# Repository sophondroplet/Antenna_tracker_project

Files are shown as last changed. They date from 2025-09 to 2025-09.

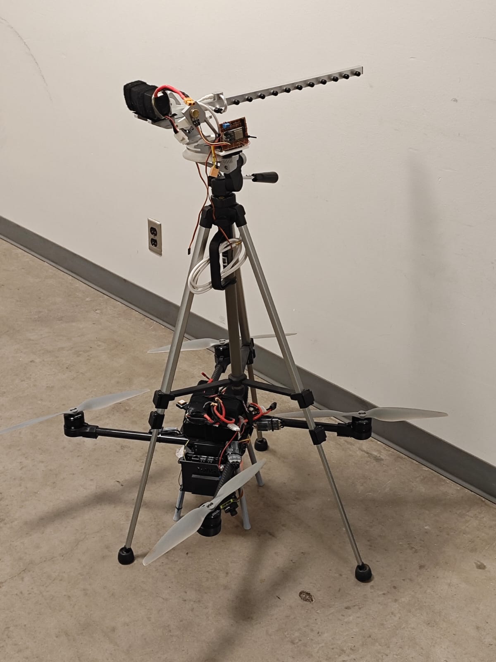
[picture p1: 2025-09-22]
assets/images/atrimg6.jpg

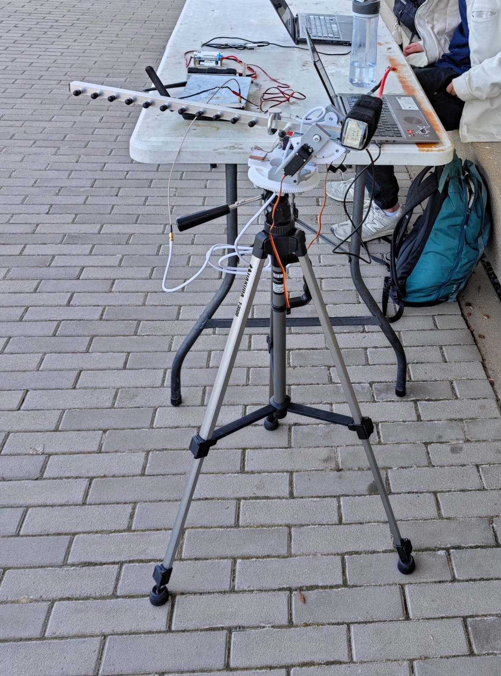
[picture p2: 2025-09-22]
assets/images/atrimg7.jpg

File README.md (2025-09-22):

# Antenna Tracker Project

## Project Overview
The Antenna Tracker Project is designed to track and maintain communication with a moving object, such as a drone or satellite, by dynamically adjusting the orientation of an antenna. This project leverages GPS data, magnetometer calibration, and servo control to achieve precise tracking.

## Directory Structure and File Descriptions

### 1. `GPS_tester/GPS_tester.ino`
This script tests the GPS module by reading and displaying latitude, longitude, and altitude data. It uses the `TinyGPS++` library to parse GPS data and outputs the results via the serial monitor.

### 2. `GPS_tester_send/GPS_tester_send.ino`
Similar to `GPS_tester.ino`, this script reads GPS data but also transmits the raw GPS data over a serial connection. It includes LED indicators for activity.

### 3. `Magentormeter_calibration/Magentormeter_calibration.py`
This Python script calibrates the magnetometer by fitting an ellipsoid to the raw data. It calculates hard iron offsets and soft iron transformation matrices to correct the magnetometer readings. The script uses libraries like `numpy`, `matplotlib`, and `scipy` for data processing and visualization.

### 4. `Main/Main.ino`
The main control script for the antenna tracker. It integrates GPS data, WiFi communication, and servo control to dynamically adjust the antenna's azimuth and elevation. Key features include:
- WiFi setup for communication with a ground station.
- UDP packet handling for receiving GPS coordinates.
- Servo motor control for antenna orientation.
- Calibration parameters for precise tracking.

### 5. `Servo_tester/Servo_tester.ino`
This script tests the servo motors by allowing manual control via the serial monitor. Users can input PWM values to adjust the servo position and observe the response.

### 6. `UDP_GPS_send_tester/UDP_GPS_send_tester.ino`
This script tests the UDP communication by sending GPS data over a network. It ensures that the GPS data can be transmitted and received correctly.

## Additional Resources

### CAD Files
The `CAD_files` directory contains 3D models and components for the antenna tracker. These files can be used for manufacturing or 3D printing the hardware. Key files include:
- `Antenn tracker 3D model.step`: Complete 3D model of the antenna tracker.
- `Antenna_Tracker-elevator gear.step`: Gear for the elevator mechanism.
- `Antenna_Tracker-arm_left.step` and `Antenna_Tracker-arm_right.step`: Left and right arms of the tracker.
- `Antenna_Tracker-battery holder left.step` and `Antenna_Tracker-battery holder right.step`: Battery holders.
- `Antenna_Tracker-Spur gear (18 teeth).step` and `Antenna_Tracker-Spur gear (20 teeth).step`: Spur gears for the mechanism.

### Images
The `assets/images` directory contains images of the project and CAD renderings. These images provide a visual reference for the hardware setup and design. Key images include:
- `atrCAD1.png` to `atrCAD6.png`: Rendered CAD images of the antenna tracker.
- `atrimg1.jpg` to `atrimg7.jpg`: Photos of the assembled hardware and components.

### Usage
- Use the CAD files to 3D print or manufacture the components.
- Refer to the images for assembly guidance and to understand the hardware layout.

## Setup Instructions

### Hardware Requirements
- ESP32 microcontroller
- GPS module (e.g., M10Q-250 or BN-880)
- Magnetometer
- Servo motors for azimuth and elevation control
- WiFi network for communication

### Software Requirements
- Arduino IDE
- Python 3.x
- Required Python libraries: `numpy`, `matplotlib`, `scipy`
- TinyGPS++ library for Arduino
- ESP32Servo library for Arduino

### Steps to Set Up
1. **Install Arduino IDE**
   - Download and install the Arduino IDE from [arduino.cc](https://www.arduino.cc/).

2. **Install Required Libraries**
   - Open the Arduino IDE and go to `Sketch > Include Library > Manage Libraries`.
   - Search for and install the following libraries:
     - `TinyGPS++`
     - `ESP32Servo`

3. **Upload Scripts**
   - Connect the ESP32 to your computer via USB.
   - Open the desired `.ino` file in the Arduino IDE.
   - Select the correct board (`ESP32 Dev Module`) and port from the `Tools` menu.
   - Click the upload button to flash the script onto the ESP32.

4. **Calibrate the Magnetometer**
   - Connect the magnetometer to your computer.
   - Run `Magentormeter_calibration.py` using Python.
   - Follow the on-screen instructions to collect and calibrate data.

5. **Test Components**
   - Use `GPS_tester.ino` to verify GPS functionality.
   - Use `Servo_tester.ino` to test servo motor control.
   - Use `UDP_GPS_send_tester.ino` to test UDP communication.

6. **Run the Main Script**
   - Upload `Main.ino` to the ESP32.
   - Ensure all hardware components are connected.
   - Monitor the serial output for debugging and status updates.

## Notes
- Ensure the GPS module is connected to the correct pins as specified in the scripts.
- Calibration values for the magnetometer and servos may need to be adjusted based on your setup.
- The WiFi credentials in `Main.ino` should be updated to match your network.

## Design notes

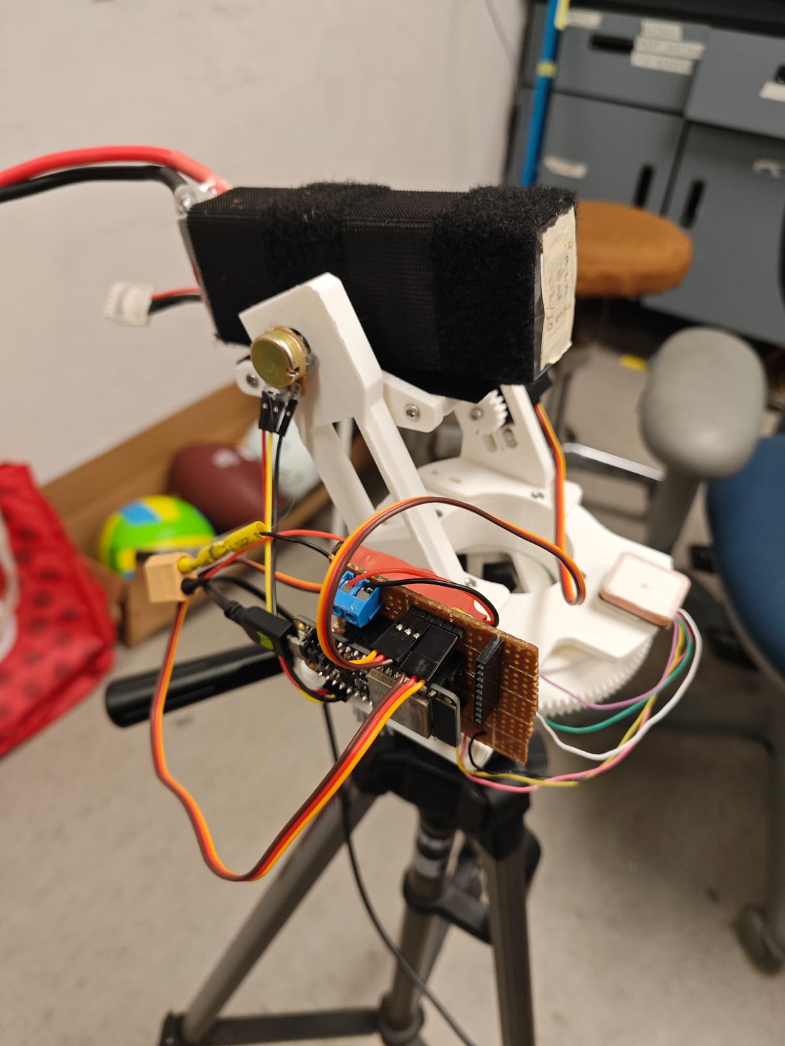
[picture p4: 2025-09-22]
assets/images/atrimg5.jpg

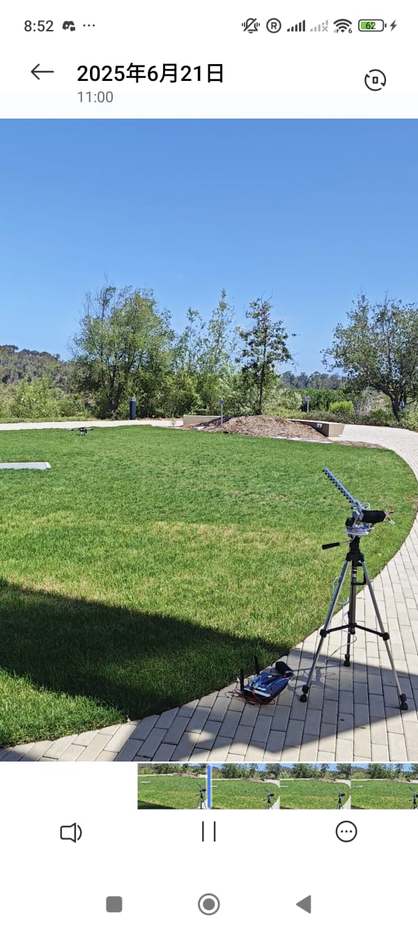
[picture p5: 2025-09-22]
assets/images/atrimg1.jpg

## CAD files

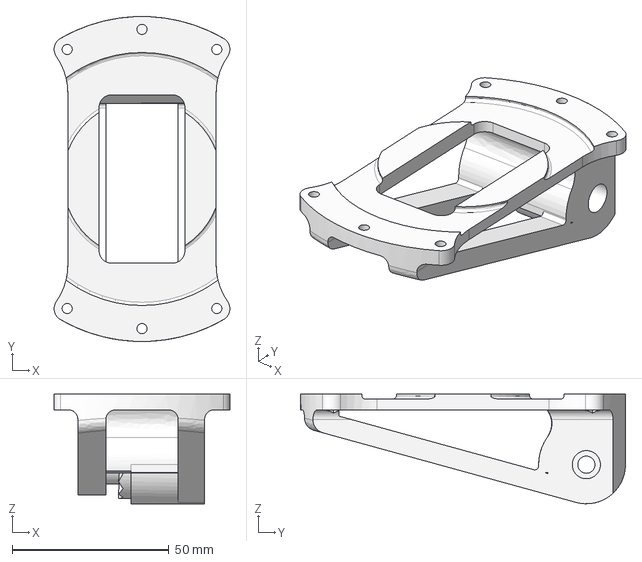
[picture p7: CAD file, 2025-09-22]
CAD_files/3d_model/Antenna_Tracker-Tripod holder main.step
56.1 x 103.8 x 35.0 mm

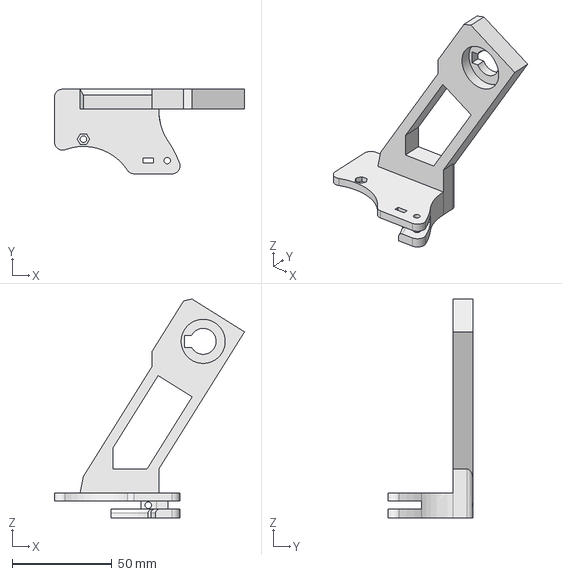
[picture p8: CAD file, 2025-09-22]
CAD_files/3d_model/Antenna_Tracker-arm_right.step
95.2 x 42.4 x 109.7 mm

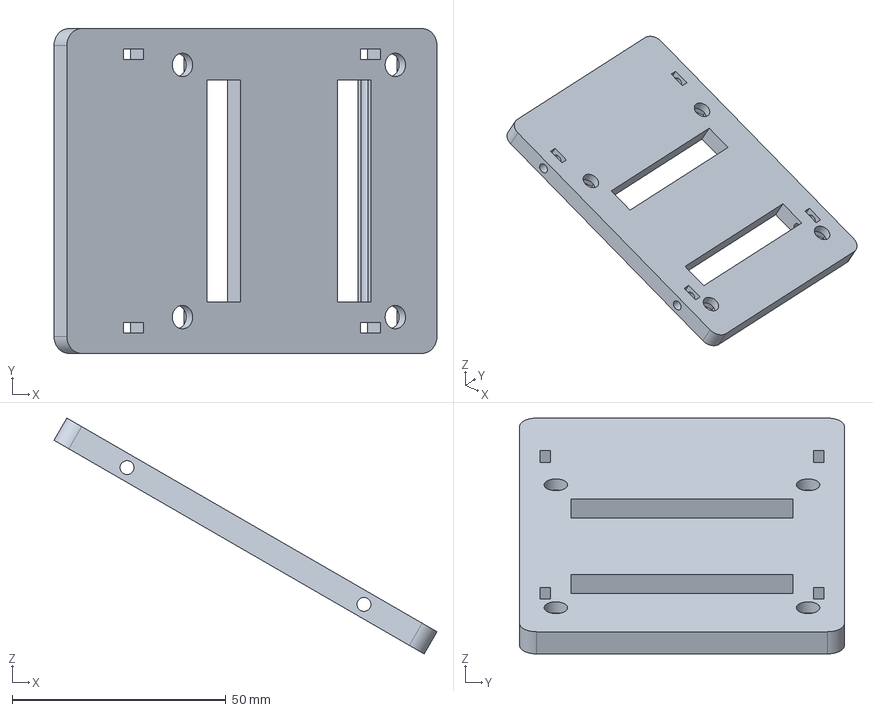
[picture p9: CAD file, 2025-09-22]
CAD_files/3d_model/Antenna_Tracker-elevator platform.step
89.6 x 76.0 x 55.2 mm

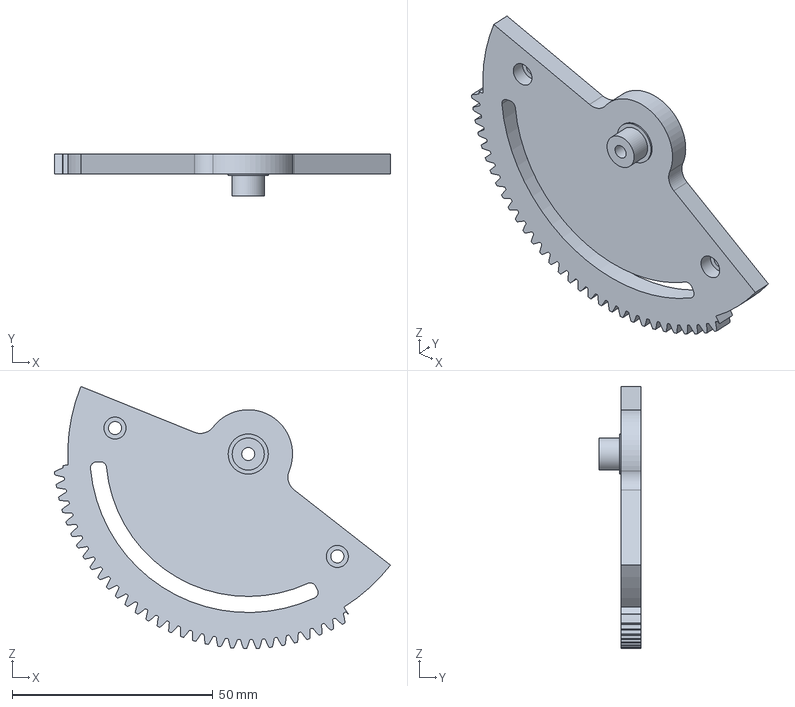
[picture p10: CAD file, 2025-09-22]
CAD_files/3d_model/Antenna_Tracker- elevator gear.step
83.8 x 10.5 x 65.4 mm

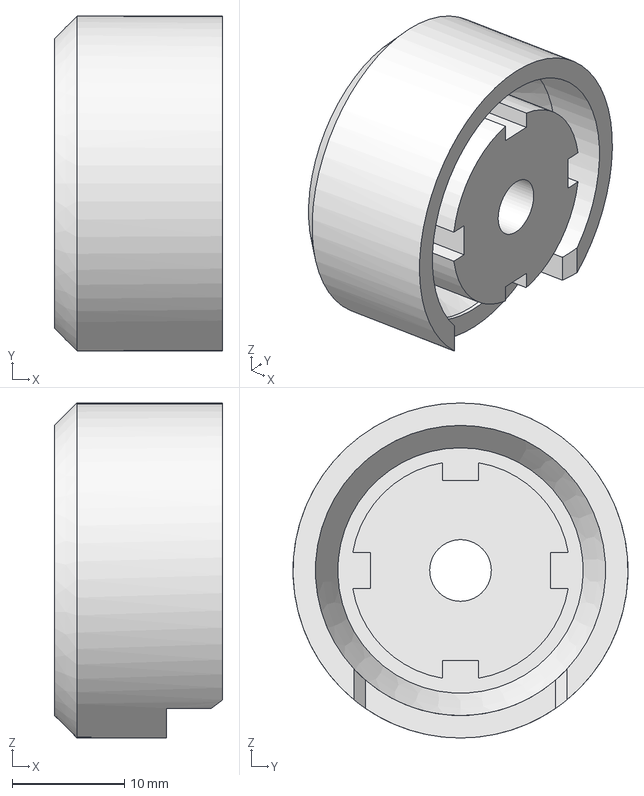
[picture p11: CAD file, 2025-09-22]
CAD_files/3d_model/Antenna_Tracker-Tripod_holder_cap.step
15.0 x 29.9 x 29.9 mm

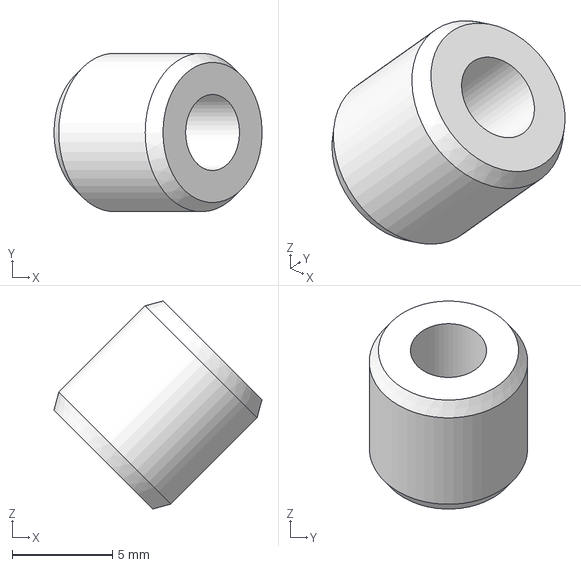
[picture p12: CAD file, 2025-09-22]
CAD_files/3d_model/Antenna_Tracker-Roller (x30).step
10.4 x 7.92 x 10.4 mm

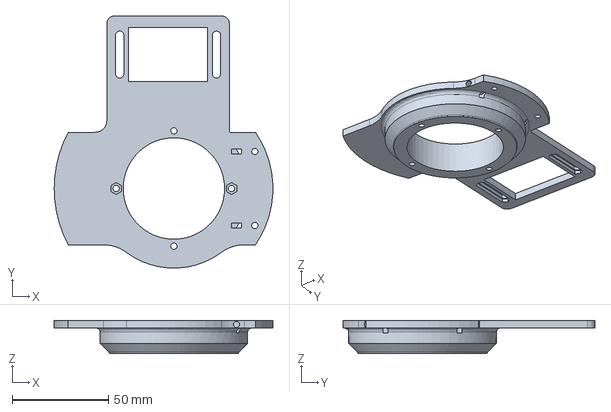
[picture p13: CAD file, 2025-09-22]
CAD_files/3d_model/Antenna_Tracker-bearing_inner_top.step
113.4 x 130.7 x 17.2 mm

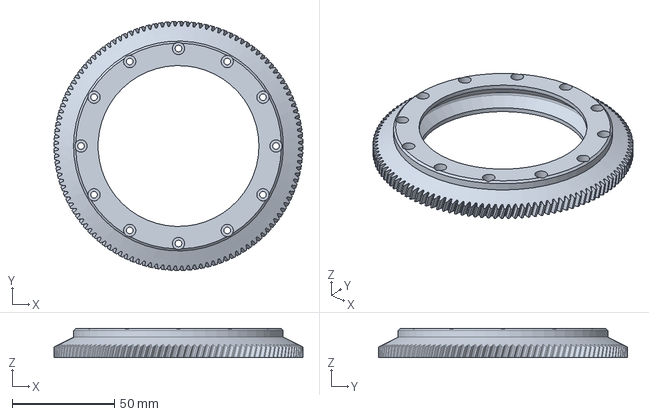
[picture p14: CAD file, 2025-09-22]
CAD_files/3d_model/Antenna_Tracker-bearing_outer.step
122.0 x 122.0 x 14.3 mm

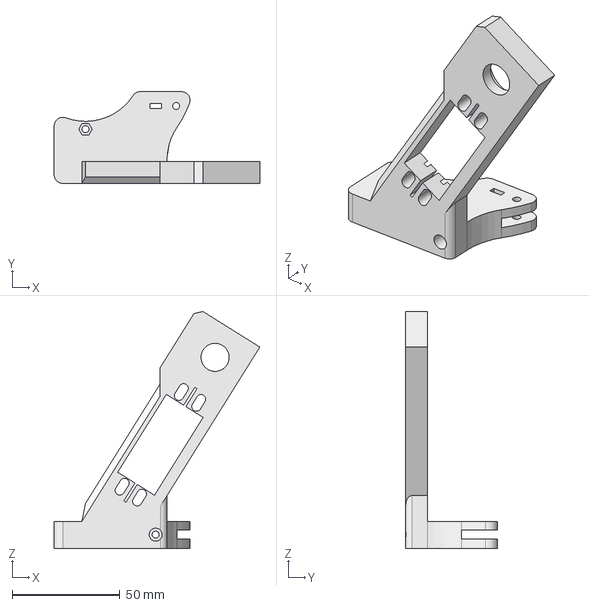
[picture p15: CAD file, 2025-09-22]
CAD_files/3d_model/Antenna_Tracker-arm_left.step
95.2 x 42.4 x 109.7 mm

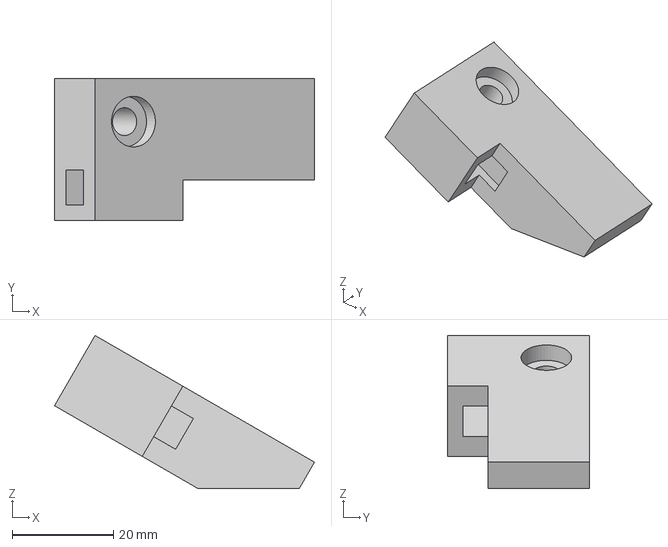
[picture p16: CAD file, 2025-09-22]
CAD_files/3d_model/Antenna_Tracker-battery holder right.step
51.3 x 28.0 x 30.2 mm

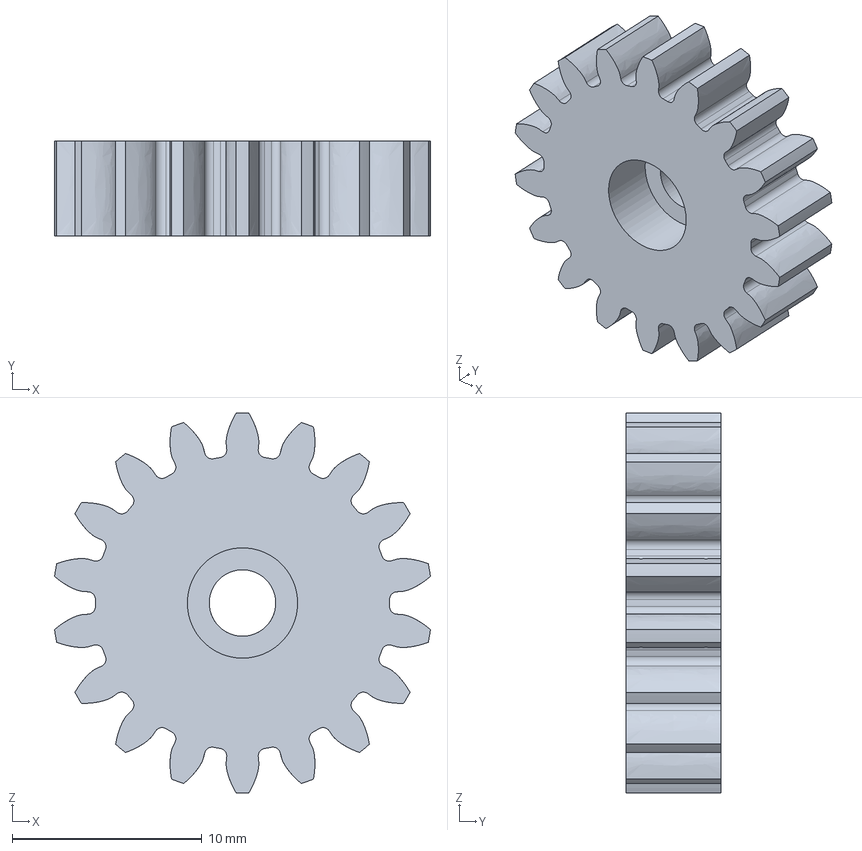
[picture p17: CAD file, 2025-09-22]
CAD_files/3d_model/Antenna_Tracker-Spur gear (18 teeth).step
19.8 x 5.00 x 20.0 mm

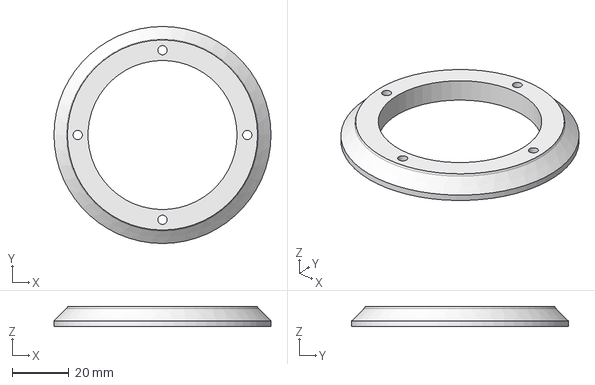
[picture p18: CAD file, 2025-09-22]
CAD_files/3d_model/Antenna_Tracker-bearing_inner_bottom.step
76.6 x 76.6 x 7.16 mm

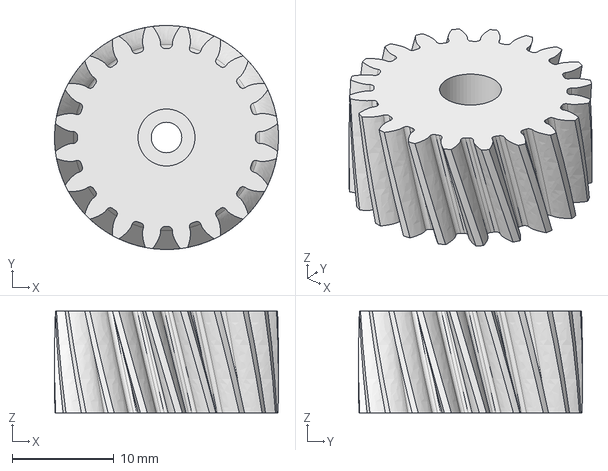
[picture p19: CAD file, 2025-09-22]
CAD_files/3d_model/Antenna_Tracker-Spur gear (20 teeth).step
22.0 x 22.0 x 10.0 mm

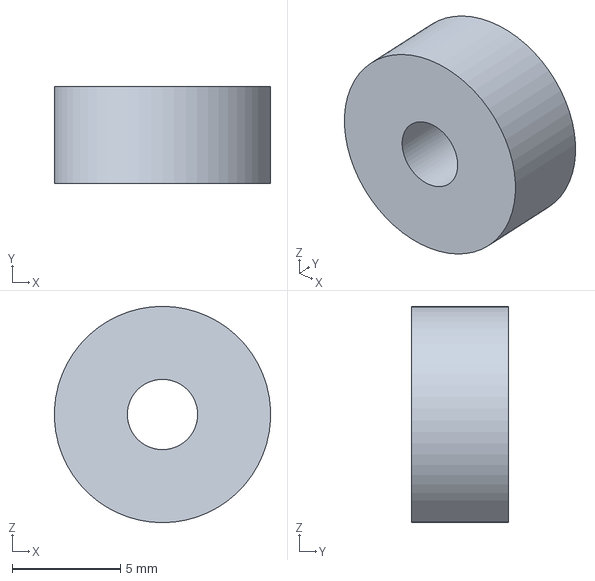
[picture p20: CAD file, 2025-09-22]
CAD_files/3d_model/Antenna_Tracker-spacer.step
9.99 x 4.50 x 10.0 mm

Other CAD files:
CAD_files/3d_model/Antenna_Tracker-elevator side.step
CAD_files/3d_model/Antenna_Tracker-battery holder left.step

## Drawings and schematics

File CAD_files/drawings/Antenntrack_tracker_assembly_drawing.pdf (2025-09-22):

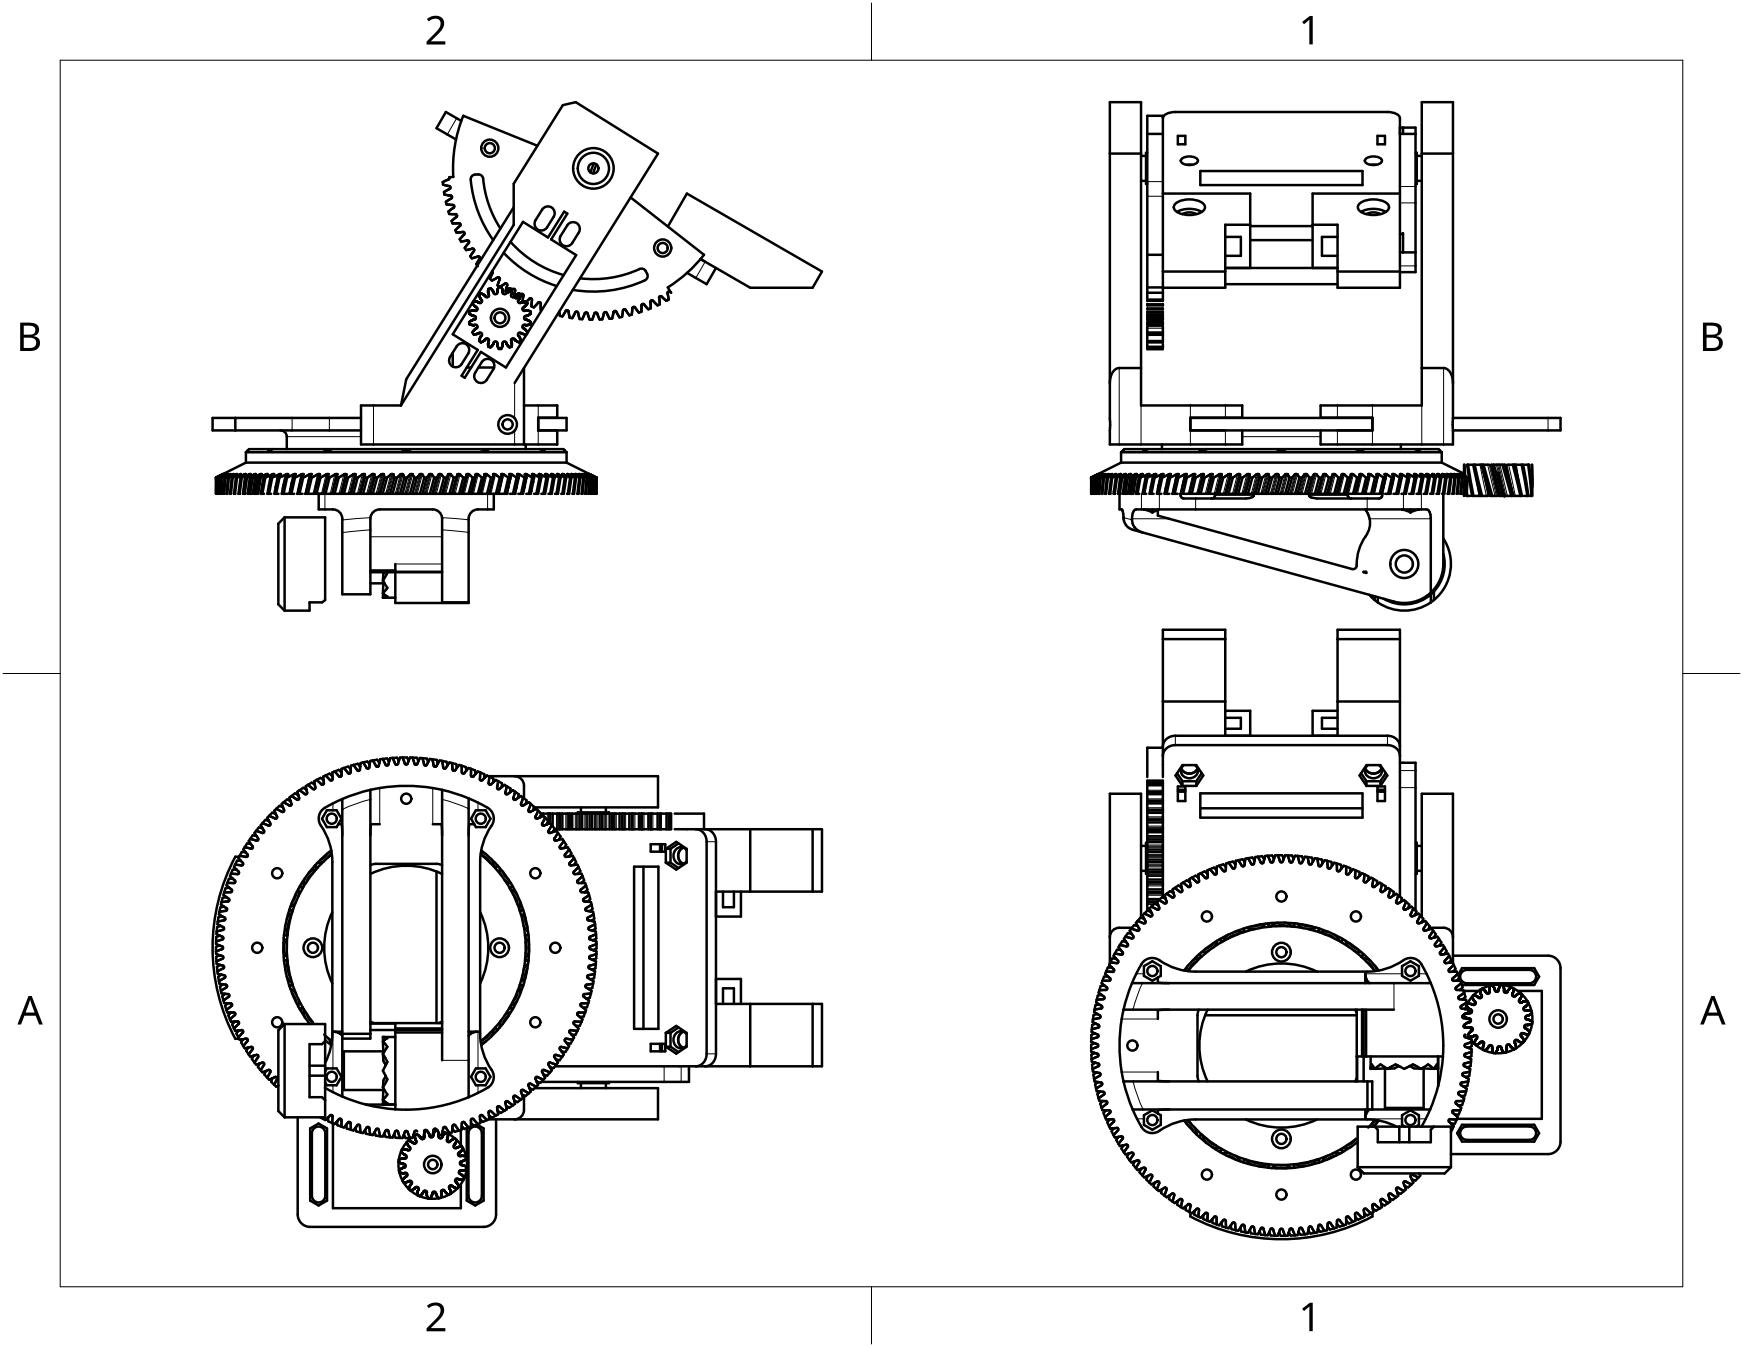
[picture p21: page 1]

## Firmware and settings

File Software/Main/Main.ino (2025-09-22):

#include <Wire.h>
#include <TinyGPS++.h>
#include <SPI.h>
#include <ESP32Servo.h>
#include <WebServer.h>
#include <WiFi.h>
#include <WiFiUdp.h>
#include <HardwareSerial.h>

/*
  WARNING NOTE:

  THIS CODE WAS WRITTEN FOR USE WITH THE M10Q-250 GPS MODULE, NOT THE BN-880. CHECK WHICH IS ATTACHED BEFORE UPLOADING.
*/

#define AZIMUTH_SERVO_PIN 12
#define ELEVATION_SERVO_PIN 13 // NOTE: THIS MIGHT NEED TO BE SWAPPED WITH AZIMUTH (we forgot which one was which)
#define UDP_TX_PACKET_MAX_SIZE 64 // this might need to be 255?
#define SDA_PIN 23
#define SCL_PIN 22
#define POT_PIN 39
#define I2C_ADDR 0x0D
#define GPS_BAUD_RATE 115200

// these values are found with the servo tester
#define AZIMUTH_MID_PWM 1431 //Azumith (>1437 clockwise, 1426<=stop<=1437)
#define ELEVATOR_MID_PWM 1533 //Elevator (>1542 angle down, 1524<=stop=<1542)

// these values calibrated at the la quinta inn in maryland on 6/25/2024, using the calibration script within the antenna tracker repo
// #define X_OFFSET -140
// #define Y_OFFSET -47

// these values calibrated at the TUAS lab on 6/14/2025, using the calibration script within the antenna tracker repo
// #define X_OFFSET -300
// #define Y_OFFSET 3
// #define X_SCALE 1
// #define Y_SCALE 1

#define X_OFFSET -246.28
#define Y_OFFSET -26.16
#define X_SCALE 0.992223
#define Y_SCALE 1.007900

const double pi = 3.14159265359;

//set up to connect to an existing network (e.g. mobile hotspot from laptop that will run the python code)
const char* ssid = "INNOUT";
const char* password = "animalfries";
IPAddress local_IP(192, 168, 1, 36);
IPAddress gateway(192, 168, 1, 1);
IPAddress subnet(255, 255, 255, 0);
IPAddress primaryDNS(8, 8, 8, 8);
IPAddress secondaryDNS(8, 8, 4, 4); 

// Buffer to hold incoming packet, expecting "lat,lon,altitude" (in meters), default to top of Geisel
char packetBuffer[UDP_TX_PACKET_MAX_SIZE] = "32.88114,-117.23758,150";

WiFiUDP Udp;
unsigned int localUdpPort = 4000;  //  port to listen on

TinyGPSPlus gpsStation;

Servo azimuthServo;
const uint16_t azimuth_servo_min_pwm = 1100; // spin fast
const uint16_t azimuth_servo_max_pwm = 1900; // spin fast but the other way

Servo elevationServo;
const uint16_t elevation_servo_min_pwm = 1000; // up
const uint16_t elevation_servo_max_pwm = 1920; // horizon

// Filter cutoff frequency in Hz
const double headingCutoff = 5;
const double latCutoff = 0.05;
const double longCutoff = 0.05;
const double altCutoff = 0.05;

// Main loop target frequency in Hz
const double frequency = 100;

// Controller gains
const double pGain_azimuth = 6;
const double iGain_azimuth = 0;
const double dGain_azimuth = 0;

const double pGain_elevation = 10;
const double iGain_elevation = 0;
const double dGain_elevation = 0.05;

// For timing the main loop
uint32_t previousMillis;

// WGS84 - (World Geodetic System) is a standard that defines a geodetic datum for Earth. Functions that input this assume the reference ellipsoid defined by WGS84.
struct WGS84 {
  double lat; //Lattitude in radians
  double lon; //Longitude in radians
  double alt; //Altitude in meters
};

// ECEF - Earth Centered, Earth Fixed coordinate system. 0,0,0 is the center of the Earth.
struct ECEF {
  double x; //Meters in the plane of the equator in the direction of the prime meridian
  double y; //Meters in the plane of the equator in the direction of 90 degrees East
  double z; //Meters in the direction of the North pole
};

// ENU - East, North, Up coordinate system. Used to show an offset from a certain location on the Earth, usually a ground station.
struct ENU {
  double e; //Meters East from reference location
  double n; //Meters North from reference location
  double u; //Meters Up from reference location
};

// Converts a lattitude, longitude and altitude to ECEF coordinates using the WGS84 Ellipsoid
ECEF WGS84toECEF(WGS84 wgs84) {
  double a = 6378137;  //Earth semi-major axis in meters
  double b = 6356752;  //Earth semi-minor axis in meters
  double e2 = 1 - (b*b)/(a*a);
  ECEF ecef;
  ecef.x = (wgs84.alt + a/(sqrt(1-e2*sin(wgs84.lat)*sin(wgs84.lat))))*cos(wgs84.lat)*cos(wgs84.lon);
  ecef.y = (wgs84.alt + a/(sqrt(1-e2*sin(wgs84.lat)*sin(wgs84.lat))))*cos(wgs84.lat)*sin(wgs84.lon);
  ecef.z = (wgs84.alt + (1-e2)*a/(sqrt(1-e2*sin(wgs84.lat)*sin(wgs84.lat))))*sin(wgs84.lat);
  return ecef;
}

// Converts two sets of ECEF coordinates to an ENU offset from the perspective of the given lattitude and longitude
ENU ECEFtoENU(WGS84 ground, ECEF station, ECEF aircraft) {
  ECEF delta;
  delta.x = aircraft.x - station.x;
  delta.y = aircraft.y - station.y;
  delta.z = aircraft.z - station.z;
  ENU enu;
  enu.e = (delta.x)*(-sin(ground.lon)) + (delta.y)*(cos(ground.lon));
  enu.n = (delta.x)*(-sin(ground.lat)*cos(ground.lon)) + (delta.y)*(-sin(ground.lat)*sin(ground.lon)) + (delta.z)*(cos(ground.lat));
  enu.u = (delta.x)*(cos(ground.lat)*cos(ground.lon)) + (delta.y)*(cos(ground.lat)*sin(ground.lon)) + (delta.z)*(sin(ground.lat));
  return enu;
}

// PID controller
double PIDcontroller_azimuth(double state, double setPoint) {
    // Calculate error in terms of shortest path to setpoint
    double errorDegrees = -(fmod(state - setPoint + 540, 360) - 180);

    double proportional;
    static double integral;
    double derivative;
    static double previousError;

    proportional = errorDegrees;
    integral = integral + (errorDegrees / frequency);
    derivative = (errorDegrees - previousError) * frequency;
    previousError = errorDegrees;
    
    Serial.print("Azimuth error:");
    Serial.print(errorDegrees, 1);
    Serial.print("P:");
    Serial.print(pGain_azimuth*proportional, 1);
    Serial.print("  I:");
    Serial.print(iGain_azimuth*integral, 1);
    Serial.print("  D:");
    Serial.print(dGain_azimuth*derivative, 1);
    Serial.print("  ");
    
    double controllerOutput = pGain_azimuth*proportional + iGain_azimuth*integral + dGain_azimuth*derivative;
    return controllerOutput;
}



double PIDcontroller_elevation(double state, double setPoint) {
    // Calculate error in terms of shortest path to setpoint
    double errorDegrees = fmod(state - setPoint + 540, 360) - 180;

    double proportional;
    static double integral;
    double derivative;
    static double previousError;

    proportional = errorDegrees;
    integral = integral + (errorDegrees / frequency);
    derivative = (errorDegrees - previousError) * frequency;
    previousError = errorDegrees;
    
    // Serial.print("Elevetor error:");
    // Serial.print(errorDegrees, 1);
    // Serial.print("P:");
    // Serial.print(pGain_elevation*proportional, 1);
    // Serial.print("  I:");
    // Serial.print(iGain_elevation*integral, 1);
    // Serial.print("  D:");
    // Serial.print(dGain_elevation*derivative, 1);
    // Serial.print("  ");
    
    double controllerOutput = pGain_elevation*proportional + iGain_elevation*integral + dGain_elevation*derivative;
    return controllerOutput;
}

void updateFilteredGPS(WGS84& station, WGS84& station_filtered) {
  static const double latSmoothingFactor = latCutoff * 2*M_PI / frequency
                             / (1 + latCutoff * 2*M_PI / frequency);
  static const double longSmoothingFactor = longCutoff * 2*M_PI / frequency
                             / (1 + longCutoff * 2*M_PI / frequency);
  static const double altSmoothingFactor = altCutoff * 2*M_PI / frequency
                             / (1 + altCutoff * 2*M_PI / frequency);

  static bool inited = false;

  if (!inited &&
    station.lat != 0.0 &&
    station.lon != 0.0 &&
    station.alt != 0.0) 
  {
    station_filtered = station;
    inited = true;
    return;
  }

  if (!inited){
    station_filtered.lat = station.lat;
    station_filtered.lon = station.lon;
    station_filtered.alt = station.alt;
  }
    
  station_filtered.lat += latSmoothingFactor * (station.lat - station_filtered.lat);
  station_filtered.lon += longSmoothingFactor * (station.lon - station_filtered.lon);
  station_filtered.alt += altSmoothingFactor * (station.alt - station_filtered.alt);
}

/*
  Initializes the QMC5883L magnetometer and returns -1 if an error occurred, 0 otherwise.
*/
int qmc5883lInit() {
  // Reset magnetometer
  Wire.beginTransmission(I2C_ADDR);
  Wire.write(0x0A);
  Wire.write(0b10000000); // Set soft reset bit
  Wire.endTransmission();

  // Configure set/reset period (I have no idea what this does tbh but it's in the datasheet)
  Wire.beginTransmission(I2C_ADDR);
  Wire.write(0x0B);
  Wire.write(0x01);
  Wire.endTransmission();

  // Set config settings
  Wire.beginTransmission(I2C_ADDR);
  Wire.write(0x09);
  Wire.write(0b00011101); // Config register 1: continuous mode, output data rate of 200Hz, 8G scale, over sample ratio of 64
  Wire.endTransmission();

  // Basic I2C test
  Wire.beginTransmission(I2C_ADDR);
  Wire.write(0x0D);
  Wire.endTransmission();

  uint8_t chipID = 0;
  int numBytes = Wire.requestFrom(I2C_ADDR, 1);
  if (numBytes) {
    Wire.readBytes(&chipID, numBytes);
    Serial.printf("Received chip ID: %02X (expected 0xFF)\n", chipID);
  } else {
    Serial.println("ERROR: COULD NOT VERIFY CHIP ID");
  }

  if (chipID != 0xFF) {
    return -1;
  }

  return 0;
}

/*
  Waits for the QMC5883L DRDY bit to be set, then reads X, Y, and Z data from the magnetometer into the given int16_t pointers.
  Returns -1 if an error occurred in transmission and 0 otherwise.
*/
int qmc5883lGetData(int16_t* x, int16_t* y, int16_t* z) {
  // wait for DRDY bit to be set
  uint8_t status = 0;
  while (!(status & 0b00000001)) {
    Wire.beginTransmission(I2C_ADDR);
    Wire.write(0x06);
    Wire.endTransmission();

    int statusBytesReceived = Wire.requestFrom(I2C_ADDR, 1);
    if (statusBytesReceived) {
      Wire.readBytes(&status, 1);
    } else {
      Serial.println("I2C ERROR");
    }
  }

  // Data is ready, read fresh mag values
  Wire.beginTransmission(I2C_ADDR);
  Wire.write(0x00);
  Wire.endTransmission();
 
  uint8_t magData[6] = {0};
  int bytesReceived = Wire.requestFrom(I2C_ADDR, 6);
  if (bytesReceived) {
    Wire.readBytes(magData, 6);
    *x = (magData[1] << 8) | magData[0];
    *y = (magData[3] << 8) | magData[2];
    *z = (magData[5] << 8) | magData[4];
    return 0;
  } else {
    Serial.println("ERROR: no data received");
    return -1;
  }
}

void setup() {  
  //Begin serial connection to computer
  Serial.begin(115200);

  // Begin serial connection to GPS
  Serial1.begin(GPS_BAUD_RATE, SERIAL_8N1, 16, 17);

  delay(1000);


  // Initialize wifi connection to INNOUT router
  WiFi.begin(ssid,password);

  // Wait for connection
  Serial.print("Connecting to WiFi...");
  while (WiFi.status() != WL_CONNECTED) {
    delay(500);
    Serial.print(".");
  }
  Serial.println("Connected!");
  Udp.begin(localUdpPort);
  Serial.printf("Now listening at IP %s, UDP port %d\n", WiFi.localIP().toString().c_str(), localUdpPort);

  // Start I2C on corresponding Huzzah32 SDA/SCL pins
  Wire.begin(SDA_PIN, SCL_PIN);

  int magstatus = -1;
  while (magstatus != 0) {
    magstatus = qmc5883lInit();
  }

  azimuthServo.attach(AZIMUTH_SERVO_PIN);
  elevationServo.attach(ELEVATION_SERVO_PIN);

  // Stop spinning the azimuth servo and set the elevation servo to 45ish degrees
  azimuthServo.writeMicroseconds(1500);
  elevationServo.writeMicroseconds(1500);

  // Give time to read debug serial messages
  Serial.println("Setup complete");
  delay(1000);
}

void loop() {
  uint32_t currentMillis = millis();

  if (currentMillis - previousMillis >= 1000 / frequency) {
    previousMillis = currentMillis;

    // Feed characters to the gps object
    while (Serial1.available() > 0) {
      gpsStation.encode(Serial1.read());
    }

    // Calculate current elevation
    int adcValue = analogRead(POT_PIN); // Read raw value (0-4095)
    double elevation = ((double)adcValue-1104)*(90.0/(2510-1104)); //1104 = 0 deg (min), 2510 = 90 deg (max)
    Serial.print("  Elevation:");
    Serial.print(elevation);

    // Update station state
    WGS84 station;
    station.lat = gpsStation.location.lat() * pi/180;
    station.lon = gpsStation.location.lng() * pi/180;
    station.alt = gpsStation.altitude.meters();

    //Low pass filter for station coordinates 
    static WGS84 station_filtered;
    updateFilteredGPS(station, station_filtered);

    // static const double latSmoothingFactor = latCutoff * 2 * pi / frequency / (1 + 2 * pi * latCutoff / frequency);
    // static const double longSmoothingFactor = longCutoff * 2 * pi / frequency / (1 + 2 * pi * longCutoff / frequency);
    // static const double altSmoothingFactor = altCutoff * 2 * pi / frequency / (1 + 2 * pi * altCutoff / frequency);

    // static double station_filteredlat = station.lat;
    // static double station_filteredlon = station.lon;
    // static double station_filteredalt = station.alt;

    // station_filteredlat = station_filteredlat + latSmoothingFactor * (station.lat - station_filteredlat);
    // station_filteredlon = station_filteredlon + longSmoothingFactor * (station.lon - station_filteredlon);
    // station_filteredalt = station_filteredalt + altSmoothingFactor * (station.alt - station_filteredalt);

    // static WGS84 station_filtered;
    // station_filtered.lat = station_filteredlat;
    // station_filtered.lon = station_filteredlon;
    // station_filtered.alt = station_filteredalt;

    //EBU lab coordinates
    // station.lat = 32.882047 * pi/180;
    // station.lon = -117.235520 * pi/180;
    // station.alt = 128.10;

    //competition site coordinates
    // station.lat = 38.316016 * pi/180;
    // station.lon = -76.54860 * pi/180;
    // station.alt = 8.05;


    // Write new packets to packetBuffer
    uint16_t packetSize = Udp.parsePacket();
    if (packetSize) {
      // Udp.read(packetBuffer, UDP_TX_PACKET_MAX_SIZE);

      int bytesRead = Udp.read(packetBuffer, UDP_TX_PACKET_MAX_SIZE - 1);
      packetBuffer[bytesRead] = '\0';

      Serial.print("Bytes read: ");
      Serial.println(bytesRead);
    }

    Serial.print("Packet received: ");
    Serial.println(packetBuffer);

    // Update aircraft state
    WGS84 aircraft;
    char packetParse[UDP_TX_PACKET_MAX_SIZE];
    strcpy(packetParse, packetBuffer);
    char *token;
    token = strtok(packetParse, ",");
    aircraft.lat = String(token).toDouble() * pi / 180;
    token = strtok(NULL, ",");
    aircraft.lon = String(token).toDouble() * pi / 180;
    token = strtok(NULL, ",");
    aircraft.alt = String(token).toDouble();

    // Calculate ENU offset from station to aircraft
    ENU enu = ECEFtoENU(station, WGS84toECEF(station_filtered), WGS84toECEF(aircraft));

    // Get mag data
    int16_t magXVal = 0;
    int16_t magYVal = 0;
    int16_t magZVal = 0;
    int status = qmc5883lGetData(&magXVal, &magYVal, &magZVal);
    if (status != 0) {
      Serial.println("ERROR: MAGNETOMETER DATA NOT RECEIVED");
    } else {
      double heading = -atan2((magYVal - Y_OFFSET)*Y_SCALE, (magXVal - X_OFFSET)*X_SCALE) * 180/pi; // Accounting for board orientation
      double declination = -10.9333; // For Maryland, need to implement adjustments for other locations
      heading += declination;
      // heading += 18.0;

      if (heading<-180){ 
        heading = 360 - abs(heading);
      }else if (heading>180){
        heading = -360 + abs(heading);
      }

      // Single-pole IIR low-pass filter
      static const double headingSmoothingFactor = headingCutoff * 2 * pi / frequency / (1 + 2 * pi * headingCutoff / frequency);
      static double headingFiltered = heading;
      headingFiltered = headingFiltered + headingSmoothingFactor * (heading - headingFiltered);

      // Calculate desired azimuth and elevation
      double azimuthSetpoint = atan2(enu.e, enu.n) * 180/pi;
      double elevationSetpoint = constrain(atan2(enu.u, sqrt(enu.e*enu.e + enu.n*enu.n)) * 180/pi, 0, 90);

      // Calculate PWM values to write to servos
      double controllerOutput_azimuth = PIDcontroller_azimuth(heading, azimuthSetpoint);
      double azimuthCommand = constrain(AZIMUTH_MID_PWM + controllerOutput_azimuth, azimuth_servo_min_pwm, azimuth_servo_max_pwm);
      double controllerOutput_elevation = PIDcontroller_elevation(elevation, elevationSetpoint);
      double elevationCommand = constrain(ELEVATOR_MID_PWM + controllerOutput_elevation, azimuth_servo_min_pwm, azimuth_servo_max_pwm);

      azimuthServo.writeMicroseconds(azimuthCommand);
      elevationServo.writeMicroseconds(elevationCommand);
      Serial.println("azimuth servo target: " + String(azimuthCommand));
      Serial.println("elevation servo target: " + String(elevationCommand));
      
      // Time the main loop
      static uint32_t tic;
      uint32_t toc = millis();
      uint16_t time = toc - tic;
      tic = millis();

      Serial.print("  Aircraft: ");
      Serial.print(aircraft.lat * 180 / pi, 6);
      Serial.print(", ");
      Serial.print(aircraft.lon * 180 / pi, 6);
      Serial.print(", ");
      Serial.print(aircraft.alt, 2);
      Serial.print("  Station: ");
      Serial.print(station.lat * 180 / pi, 6);
      Serial.print(", ");
      Serial.print(station.lon * 180 / pi, 6);
      Serial.print(", ");
      Serial.print(station.alt, 2);

      Serial.print("  Station Filtered: ");
      Serial.print(station_filtered.lat * 180 / pi, 6);
      Serial.print(", ");
      Serial.print(station_filtered.lon * 180 / pi, 6);
      Serial.print(", ");
      Serial.print(station_filtered.alt, 2);
      
      Serial.print("  ElevationSet:");
      Serial.print(elevationSetpoint, 2);
      Serial.print("  AzimuthSet:");
      Serial.print(azimuthSetpoint, 2);
      Serial.print("  Heading:");
      Serial.print(heading, 2);
      Serial.print("  HeadingFiltered:");
      Serial.print(headingFiltered, 2);
      Serial.print("  Time:");
      Serial.print(time);
      Serial.println();
    }
  }
}

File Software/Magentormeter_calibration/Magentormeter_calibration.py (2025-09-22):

import numpy as np
import matplotlib.pyplot as plt
from mpl_toolkits.mplot3d import Axes3D
import serial
import time
from scipy.linalg import inv, norm
from scipy.optimize import least_squares
import threading
from queue import Queue

class MagnetometerCalibrator:
    def __init__(self, serial_port, baud_rate=115200):
        self.serial_port = serial_port
        self.baud_rate = baud_rate
        self.raw_data = []
        self.calibrated_data = []
        self.calibration_params = {}
        self.data_queue = Queue()
        self.is_collecting = False
        
    def ellipsoid_fit(self, data):
        """
        Fit an ellipsoid to magnetometer data using least squares optimization
        to determine hard iron offsets and soft iron transformation matrix
        """
        # Implementation of ellipsoid fitting algorithm
        pass
        
    def calibrate_points(self, points):
        """
        Apply calibration parameters to raw magnetometer readings
        """
        # Apply calibration transformation to raw data
        pass
        
    def serial_reader(self):
        """
        Read data from serial port and add to queue
        """
        try:
            with serial.Serial(self.serial_port, self.baud_rate, timeout=1) as ser:
                print(f"Connected to {self.serial_port}. Starting data collection...")
                print("Rotate the magnetometer slowly in all possible orientations")
                
                while self.is_collecting:
                    line = ser.readline().decode('utf-8').strip()
                    if line and line.startswith('MAG:'):
                        try:
                            # Expected format: "MAG:x,y,z"
                            values = line.split(':')[1].split(',')
                            x, y, z = map(float, values)
                            self.data_queue.put((x, y, z))
                        except (ValueError, IndexError):
                            continue
        except serial.SerialException as e:
            print(f"Serial communication error: {e}")
            self.is_collecting = False

    def collect_data(self, duration=60, sample_delay=0.1):
        """
        Collect magnetometer data for specified duration
        """
        self.raw_data = []
        self.is_collecting = True
        
        # Start serial reader in a separate thread
        reader_thread = threading.Thread(target=self.serial_reader)
        reader_thread.daemon = True
        reader_thread.start()
        
        # Collect data for specified duration
        start_time = time.time()
        last_sample_time = start_time
        
        while time.time() - start_time < duration:
            if time.time() - last_sample_time >= sample_delay and not self.data_queue.empty():
                x, y, z = self.data_queue.get()
                self.raw_data.append([x, y, z])
                last_sample_time = time.time()
                
                # Print progress
                progress = (time.time() - start_time) / duration * 100
                print(f"Progress: {progress:.1f}% - Collected {len(self.raw_data)} samples", end='\r')
        
        self.is_collecting = False
        print(f"\nData collection complete. Collected {len(self.raw_data)} samples.")
        
    def perform_calibration(self):
        """
        Perform ellipsoid fitting calibration on collected data
        """
        if len(self.raw_data) < 100:
            print("Insufficient data for calibration. Need at least 100 samples.")
            return False
            
        print("Performing ellipsoid fitting calibration...")
        
        # Convert to numpy array
        data = np.array(self.raw_data)
        
        # Perform ellipsoid fitting
        # This is a simplified version - actual implementation would use
        # more sophisticated algorithms for ellipsoid fitting
        center = np.mean(data, axis=0)
        centered_data = data - center
        
        # Covariance matrix
        cov = np.cov(centered_data.T)
        
        # Eigen decomposition to find principal axes
        eigenvalues, eigenvectors = np.linalg.eig(cov)
        
        # Scaling factors (inverse of eigenvalues)
        scaling = 1.0 / np.sqrt(eigenvalues)
        
        # Store calibration parameters
        self.calibration_params = {
            'hard_iron_offset': center.tolist(),
            'soft_iron_matrix': (eigenvectors @ np.diag(scaling) @ eigenvectors.T).tolist()
        }
        
        # Apply calibration to raw data
        self.calibrated_data = self.calibrate_points(data)
        
        print("Calibration complete!")
        return True
        
    def plot_data(self):
        """
        Create 3D plots of raw and calibrated magnetometer data
        """
        if not self.raw_data:
            print("No data to plot")
            return
            
        raw_data = np.array(self.raw_data)
        calibrated_data = np.array(self.calibrated_data) if self.calibrated_data else None
        
        fig = plt.figure(figsize=(12, 5))
        
        # Plot raw data
        ax1 = fig.add_subplot(121, projection='3d')
        ax1.scatter(raw_data[:, 0], raw_data[:, 1], raw_data[:, 2], 
                   c='r', marker='o', alpha=0.5, label='Raw Data')
        ax1.set_title('Raw Magnetometer Data')
        ax1.set_xlabel('X')
        ax1.set_ylabel('Y')
        ax1.set_zlabel('Z')
        ax1.legend()
        
        # Plot calibrated data if available
        if calibrated_data is not None:
            ax2 = fig.add_subplot(122, projection='3d')
            ax2.scatter(calibrated_data[:, 0], calibrated_data[:, 1], calibrated_data[:, 2], 
                       c='b', marker='o', alpha=0.5, label='Calibrated Data')
            ax2.set_title('Calibrated Magnetometer Data')
            ax2.set_xlabel('X')
            ax2.set_ylabel('Y')
            ax2.set_zlabel('Z')
            ax2.legend()
            
            # Calculate and display calibration metrics
            radii = np.linalg.norm(calibrated_data, axis=1)
            avg_radius = np.mean(radii)
            std_radius = np.std(radii)
            
            print(f"Calibration Results:")
            print(f"Average radius: {avg_radius:.2f}")
            print(f"Standard deviation: {std_radius:.2f}")
            print(f"Hard iron offset: {self.calibration_params['hard_iron_offset']}")
        
        plt.tight_layout()
        plt.show()
        
    def save_calibration(self, filename):
        """
        Save calibration parameters to a file
        """
        if not self.calibration_params:
            print("No calibration parameters to save")
            return
            
        with open(filename, 'w') as f:
            f.write("# Magnetometer Calibration Parameters\n")
            f.write(f"HardIronOffset: {self.calibration_params['hard_iron_offset']}\n")
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

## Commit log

2025-09-22 uploaded CAD files
    [Antenna_Tracker- elevator gear.step, Antenna_Tracker-Roller (x30).step, Antenna_Tracker-Spur gear (18 teeth).step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]
2025-09-22 uploaded CAD drawings
    [Antenna_Tracker- elevator gear.step, Antenna_Tracker-Roller (x30).step, Antenna_Tracker-Spur gear (18 teeth).step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]
